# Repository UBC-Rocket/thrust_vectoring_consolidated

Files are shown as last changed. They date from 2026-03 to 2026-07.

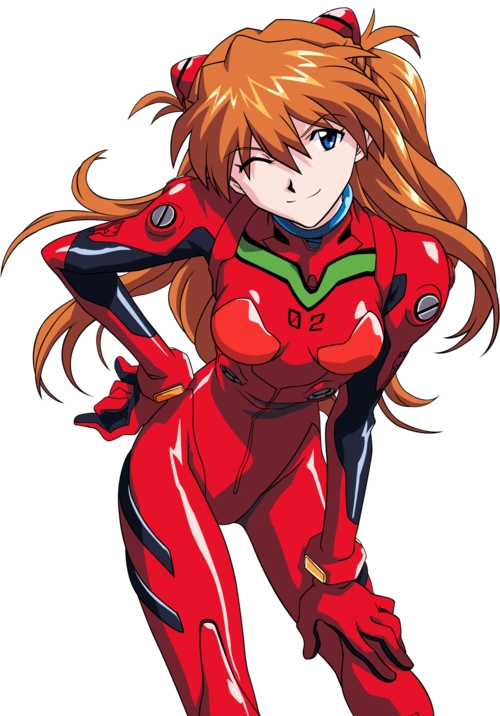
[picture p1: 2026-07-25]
embedded-software/ground-station/Resources/images/asuka.png

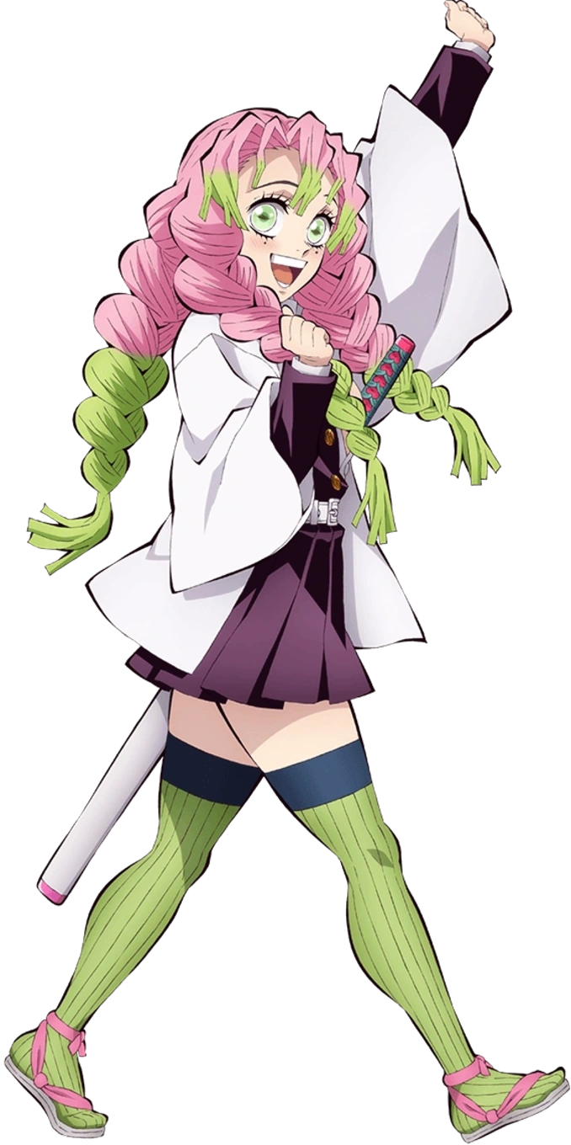
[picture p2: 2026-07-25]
embedded-software/ground-station/Resources/images/mitsuri.png

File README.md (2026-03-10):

# TVR - UBC Rocket







Mono-repo for the TVR project, containing firmware, ground station, shared libraries, and tools.

## Repository Structure

| Directory | Description |
|---|---|
| `embedded-software/firmware/ulysses-flight-controller/` | STM32H563 flight controller firmware (FreeRTOS, CMake) |
| `embedded-software/firmware/ulysses-gnss-radio/` | STM32G0xx GNSS/radio module firmware |
| `embedded-software/firmware/libs/` | Shared firmware libraries (EKF, controls, sensors, GPS) |
| `embedded-software/firmware/docs/` | Firmware documentation |
| `embedded-software/firmware/tools/` | SD log decoding and serial debug tools |
| `embedded-software/ground-station/` | Qt6/QML ground control station |
| `embedded-software/libs/rocket-protocol/` | Shared protobuf protocol library (nanopb, COBS, CRC) |
| `embedded-software/jetson/` | Future Jetson compute module (placeholder) |
| `controls/` | MATLAB/Simulink control system prototyping |
| `electrical-hardware/` | Electrical hardware design files |
| `mechanical-hardware/` | Mechanical hardware design files |

## Getting Started

For firmware development, open the board folder directly in VS Code:

- `embedded-software/firmware/ulysses-flight-controller/`
- `embedded-software/firmware/ulysses-gnss-radio/`

Each folder is self-contained with CMake presets, debug launch configs, and recommended extensions. See [embedded-software/firmware/docs/development_setup.md](embedded-software/firmware/docs/development_setup.md) for full setup instructions.

### Teams & Code Ownership

Each directory is owned by a subteam — see [CONTRIBUTING.md](CONTRIBUTING.md) for the branching model, team leads, and PR review requirements.

### Prerequisites

- ARM GCC toolchain (`arm-none-eabi-gcc`) for firmware
- STM32CubeIDE (for ST's OpenOCD — see [development setup](embedded-software/firmware/docs/development_setup.md))
- CMake 3.22+ and Ninja
- Qt 6.6+ for ground station
- Python 3.10+ with [uv](https://docs.astral.sh/uv/) for tools

### Environment Variables

Debugging requires two environment variables set in your shell profile (`~/.bashrc`, `~/.zshrc`, or `~/.config/fish/config.fish`). Both paths come from your STM32CubeIDE installation — the plugin version in the path varies by release.

| Variable | Purpose |
|---|---|
| `STM32_OPENOCD_PATH` | Path to the OpenOCD binary bundled with STM32CubeIDE |
| `STM32_OPENOCD_SCRIPTS_PATH` | Path to the OpenOCD st_scripts directory |

<details>
<summary>macOS</summary>

```bash
export STM32_OPENOCD_PATH="/Applications/STM32CubeIDE.app/Contents/Eclipse/plugins/com.st.stm32cube.ide.mcu.externaltools.openocd.macos64_<version>/tools/bin/openocd"
export STM32_OPENOCD_SCRIPTS_PATH="/Applications/STM32CubeIDE.app/Contents/Eclipse/plugins/com.st.stm32cube.ide.mcu.debug.openocd_<version>/resources/openocd/st_scripts"
```

</details>

<details>
<summary>Windows</summary>

```bash
export STM32_OPENOCD_PATH="D:/ST/STM32CubeIDE_<version>/STM32CubeIDE/plugins/com.st.stm32cube.ide.mcu.externaltools.openocd.win32_<version>/tools/bin/openocd.exe"
export STM32_OPENOCD_SCRIPTS_PATH="D:/ST/STM32CubeIDE_<version>/STM32CubeIDE/plugins/com.st.stm32cube.ide.mcu.debug.openocd_<version>/resources/openocd/st_scripts"
```

</details>

<details>
<summary>Linux</summary>

```bash
export STM32_OPENOCD_PATH="/opt/st/stm32cubeide_<version>/plugins/com.st.stm32cube.ide.mcu.externaltools.openocd.linux64_<version>/tools/bin/openocd"
export STM32_OPENOCD_SCRIPTS_PATH="/opt/st/stm32cubeide_<version>/plugins/com.st.stm32cube.ide.mcu.debug.openocd_<version>/resources/openocd/st_scripts"
```

</details>

> [!IMPORTANT]
> Restart VS Code (and your shell) after setting these variables.

### Building Firmware

```bash
cd embedded-software/firmware/ulysses-flight-controller
cmake --preset debug
cmake --build --preset debug
```

### Running Tests

```bash
# State estimation tests
cd embedded-software/firmware/libs/state_estimation/tests
cmake -B build && cmake --build build
ctest --test-dir build

# Controls tests
cd embedded-software/firmware/libs/controls/tests
cmake -B build && cmake --build build
ctest --test-dir build
```

### Building Ground Station

```bash
cd embedded-software/ground-station
cmake -B build
cmake --build build
```

## Releases

Tags follow the format `<component>/v<semver>`:
- `firmware-fc/v1.0.0` — Flight controller firmware
- `firmware-gnss/v1.0.0` — GNSS radio firmware
- `ground-station/v1.0.0` — Ground control station
- `tvr/v1.0.0` — Coordinated release of all components

## Contributors

<a href="https://github.com/UBC-Rocket/thrust_vectoring_consolidated/graphs/contributors">
  
</a>

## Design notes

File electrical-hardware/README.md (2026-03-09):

# Electrical Hardware

PCB designs, schematics, and release versions of TVR electrical hardware.

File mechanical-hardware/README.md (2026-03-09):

# Mechanical Hardware

CAD models and release versions of TVR mechanical hardware (.step files).

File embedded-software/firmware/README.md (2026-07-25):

# Firmware

All embedded firmware and shared libraries for the TVR project.

## Layer model

```
APP   app/                 hardware-agnostic tasks, state exchange, log service
DEV   dev/                 per-device drivers (opaque singletons)
IO    io/                  transport layer (SPI/UART/EXTI/DShot) +
                           system services (timestamp/intercore/LED/SD/init)
HW    flight_controller/   CubeMX project — STM32H747 dual-core (CM4 + CM7)
                           includes HAL, FreeRTOS, peripheral init
```

Plus:

| Top-level | Purpose |
|---|---|
| `lib/` | Pure-C utility libs (controls, state_estimation, log_records, …) |
| `sil/` | (placeholder) future POSIX SIL backend for the IO layer |
| `docs/` | Architecture proposals, peripheral notes, driver notes |
| `depracated/` | Old H5 flight controller + G0 GNSS daughter board, retained for reference |
| `tools/` | Host-side Python tools (SD log decoding, serial debug) |

## Building (on-target)

The CubeMX project at `flight_controller/` orchestrates two `ExternalProject`
sub-builds (one per core) for the STM32H745 dual-core target (CM7 + CM4).

```sh
./build.sh
./flash.sh    # requires STM32_OPENOCD_PATH and STM32_OPENOCD_SCRIPTS_PATH
```

`build.sh` accepts an optional preset (`Debug` or `Release`, default `Debug`) and
core filter (`both`, `cm7`, or `cm4`, default `both`). `flash.sh` uses the same
arguments to select which ELF(s) to program.

Equivalent raw CMake commands:

```sh
cd flight_controller
cmake --preset Debug && cmake --build --preset Debug
```

Each per-core build pulls in `io/`, `dev/`, `app/`, and `lib/` via
`add_subdirectory` — they don't need to be configured separately.

## Testing (host)

```sh
cd lib/controls/tests         && cmake -B build && cmake --build build && ./build/test_controls
cd lib/state_estimation/tests && cmake -B build && cmake --build build && ./build/test_state_estimation
```

## Further reading

- [`docs/architecture_layers.md`](docs/architecture_layers.md) — the HW / IO / DEV / APP layer proposal
- [`docs/spi_dma_overview.md`](docs/spi_dma_overview.md) — SPI job queue + DMA
- [`docs/sd_logging_overview.md`](docs/sd_logging_overview.md) — binary log design

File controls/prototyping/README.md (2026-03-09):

# Controls Prototyping

MATLAB/Simulink models and analysis scripts for control system design.

The production C implementations live in `firmware/libs/controls/` (PID controller, flight controller with torque control, control allocation, and gimbal angle computation).

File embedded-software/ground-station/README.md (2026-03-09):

# Ulysses Ground Control Station (GCS)
### *Real-Time Telemetry • Serial Radio Interface • 3D Rocket Visualization*

The **Ulysses Ground Control Station** is a cross-platform telemetry and control application built with **Qt 6**, designed for UBC Rocket's development and mission operations.  
It provides real-time serial communication with RFD900x radio modems, sensor telemetry decoding, 3D visual orientation, system alerts, and modular UI panels optimized for engineering workflows.

---

## 🚀 Features

### 📡 Dual-Mode Serial Communication

#### **1. Single-Port Mode**
- One COM port handles **both RX and TX**
- Automatic **RX pause** during TX to prevent echo/loopback issues
- Ideal for bench testing with a single modem

#### **2. Dual-Port Mode**
- Dedicated RX and TX ports
- Per-port capabilities:
  - Separate baud settings
  - Periodic command sender (1–200 Hz)
  - Manual send panel
  - Real-time text logging
  - Independent connect/disconnect

---

### 📶 RFD900x Modem Integration
- Automatic scanning of COM ports
- FTDI + CP210x radio-adapter detection
- AT-mode probing (`+++` guard sequence)
- OS error reporting displayed in UI
- Prevents assigning same port to both P1 and P2

---

### 📊 Sensor Telemetry Parsing

Incoming telemetry is 14-field CSV:
x, y, z,
roll, pitch, yaw,
pressure, altitude,
raw_angle, filtered_angle,
velocity, temperature, signal, battery

Decoded into:

- **IMU:** linear accel (x,y,z) + gyro (roll, pitch, yaw)
- **Barometer:** pressure, altitude
- **Kalman:** raw angle, filtered angle
- **Telemetry:** velocity, temperature, signal, battery

Each value updates QML-bound properties via `SensorDataModel`.

---

### 🛰️ 3D Rocket Visualization
Built with **Qt Quick 3D**:

- Real-time orientation driven by IMU data  
- Euler rotation mapped for Qt’s Y-up coordinate system  
- Axis helper lines  
- WASD camera movement  
- Clear visualization of rocket tilt/roll

---

### ⚠️ System Alert Classification
Using `AlarmReceiver`, incoming text is classified into:

- **ERROR**
- **WARNING**
- **SUCCESS**

Displayed visually as alert chips in the System Alert panel.

---

### 🧱 Modular Architecture

#### Backend (C++)
| Component | Description |
|---|---|
| `SerialBridge` | Serial I/O layer, port scanning, RX/TX, modem detection |
| `CommandSender` | Manual & periodic command transmission |
| `AlarmReceiver` | Classifies incoming text messages |
| `SensorDataModel` | Parses CSV telemetry, exposes data to QML |

#### Frontend (QML)
| File | Purpose |
|---|---|
| `Panel_Control.qml` | Serial configuration + TX console |
| `Panel_IMU_Data.qml` | IMU vector display |
| `Panel_Baro_And_Telemetry.qml` | Pressure, altitude, velocity, temp |
| `Panel_Rocket_Visualization.qml`  | 3D visualization of rocket |
| `Panel_System_Alert.qml` | Error/Warning/Success logs |
| `Items/` | Reusable UI components |

---

## 📁 Project Structure

/
├── src/
│ ├── SerialBridge.h/.cpp
│ ├── CommandSender.h/.cpp
│ ├── AlarmReceiver.h/.cpp
│ ├── SensorDataModel.h/.cpp
│ └── main.cpp
│
└── qml/
├── Panel_Control.qml
├── Panel_IMU_Data.qml
├── Panel_Baro_And_Telemetry.qml
├── Panel_Rocket_Visualization.qml
├── Panel_System_Alert.qml
├── Items/
└── MainWindow.qml

---

## 🧰 Build Instructions

### Requirements
- Qt **6.6+** (must include Qt Quick and Qt Quick 3D)
- CMake (Qt Creator recommended)
- Windows / macOS / Linux

### Build using Qt Creator
File → Open Project → CMakeLists.txt
Configure Kits → Desktop Qt 6.x.x
Build → Run

### Build using terminal
```bash
cmake -B build -S .
cmake --build build
./build/ulysses-ground-control     # or .exe on Windows

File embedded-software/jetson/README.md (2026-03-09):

# Jetson Compute Module

Placeholder for the future Jetson compute module. This will communicate with the flight controller via protobuf (transport TBD).

## Structure

- `src/` - Application code
- `deploy/` - Deployment scripts, Dockerfiles, flash utilities

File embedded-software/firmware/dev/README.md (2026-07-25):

# DEV layer

Per-device drivers. Each driver is a self-contained opaque singleton that
owns its EXTI handler, init sequence, sample ring, and IO bindings.

| Driver dir | Lib target | Header | Device | IO bindings |
|---|---|---|---|---|
| `imu_bmi088/` | `dev_imu_bmi088` | `dev_imu_bmi088.h` | Bosch BMI088 IMU | SPI4 + BMI_ACC_CS / BMI_GYRO_CS + INT1 lines |
| `imu_icm40609/`  | `dev_imu_icm40609`  | `dev_imu_icm40609.h`  | TDK InvenSense ICM-40609-D | SPI3 (HW NSS) + ICM_INT1 |
| `baro_ms5611/` | `dev_baro_ms5611` | `dev_baro_ms5611.h` | TE MS5611 barometer | SPI2 (HW NSS) |
| `gps_nmea/` | `dev_gps_nmea` | `dev_gps_nmea.h` | u-blox SAM-M10Q GPS (NMEA) | UART5, `'\n'` framing |
| `radio_rfd900/`  | `dev_radio_rfd900`  | `dev_radio_rfd900.h`  | RFDesign RFD900x telemetry | UART7, `0x00` framing |
| `servo_feetech/` | `dev_servo_feetech` | `dev_servo_feetech.h` | Feetech STS/SCS bus servos | UART8, half-duplex |
| `esc_dshot/` | `dev_esc_dshot` | `dev_esc_dshot.h` | DShot ESC pair | DShot upper/lower channels |

## API pattern

Every driver is an opaque singleton with the same five-call shape:

```c
#include "dev_imu_bmi088.h"

bool            imu_bmi088_init(void);                       /* IO bindings baked in */
imu_bmi088_t   *imu_bmi088_get (void);                       /* NULL before init */
size_t          imu_bmi088_drain(imu_bmi088_t *d, imu_sample_t *out, size_t max);
void            imu_bmi088_set_notify(imu_bmi088_t *d, io_task_handle_t t, uint32_t bit);
```

The struct is forward-declared in the public header; its definition lives
in the .c. Each driver references its IO transport symbols by name
(`IO_SPI_BMI088_ACC`, `IO_EXTI_BMI088_ACC_INT1`, …) which are declared in
`io/io_*.h` and defined per-target in `io/h747/CM{4,7}/`.

## Test hooks

Each driver's `s_self` singleton (and key scratch buffers, where applicable)
is exposed via `IO_TEST_HOOK_RW` / `IO_TEST_HOOK_ARRAY` macros from
[`io/io_sys/io_test_hooks.h`](../io/io_sys/include/io_sys/io_test_hooks.h).
The macros compile to nothing in production; tests link with
`-DIO_TEST_HOOKS` to access the underlying state.

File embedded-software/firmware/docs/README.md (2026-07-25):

# Firmware Documentation

Technical documentation for the TVR firmware.

- [Development Setup](development_setup.md) - Toolchain and environment setup
- [SPI DMA Overview](spi_dma_overview.md) - SPI bus architecture with DMA transfers
- [SD Logging Overview](sd_logging_overview.md) - Binary logging system design
- [Architecture: HW / IO / Dev / App Layers](architecture_layers.md) - Proposed layering and encapsulation (not yet approved)
- [Layer Hardening Proposal (v1)](layer_hardening_proposal.md) - **superseded** by `architecture_layers.md`
- `drivers/` - Sensor driver documentation
- `filtering/` - EKF and signal processing notes
- `peripherals/` - MCU peripheral configuration docs

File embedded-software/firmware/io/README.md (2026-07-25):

# IO layer

Transport between hardware peripherals and device drivers. Drivers and the
app code program against the headers in [`io/include/io/`](io/include/io/)
(transport — SPI, UART, EXTI, DShot) and [`io_sys/include/io_sys/`](io_sys/include/io_sys/)
(system services — timestamp, intercore, status LED, SD, init, shared types).

## Contents

| Path | What |
|---|---|
| `io/` | `io` interface lib — transport headers (DEV-only) |
| `io_sys/` | `io_sys` interface lib — system-service headers (APP + DEV) |
| `io_spi_queue/` | Generic SPI job-queue helper used by per-target SPI impls |
| `io_uart_dma_cm/` | DMA-circular + character-match UART helper |
| `io_intercore_slot/` | Seqlock shared-memory primitive for the H747 dual-core |
| `h747/CM4/` | H747 CM4 IO impl (defines IO_SPI_*, IO_UART_*, IO_EXTI_* symbols) |
| `h747/CM7/` | H747 CM7 IO impl |

## SIL substitution

The IO layer is the only place a SIL backend needs to replace. Add a peer
target dir (e.g. `sil/`) defining the same `IO_*` const symbols and the same
`io_*` functions; everything above (DEV, APP) links unchanged.

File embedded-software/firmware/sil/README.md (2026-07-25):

# SIL backend

Placeholder for a future POSIX/Linux software-in-the-loop implementation of
the IO layer. A SIL build mirrors `io/h747/` with simulated SPI, UART, EXTI,
and DShot impls; the `dev/` and `app/` layers above link unchanged.

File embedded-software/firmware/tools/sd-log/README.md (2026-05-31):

# SD Card Log Tools

Tools for decoding and visualizing flight log data from the SD card.

## Prerequisites

Install Python dependencies from the `tools/` directory:

```bash
cd embedded-software/firmware/tools
uv sync
```

## Decoding Binary SD Dumps

Extract the raw binary dump from the SD card, then decode it to JSONL:

```bash
# Decode a binary dump (auto-detect latest flight)
python sd-log/decode_log.py /path/to/dump.bin --latest-flight --output sd-log/logs/flight.jsonl

# Decode a specific flight by magic number
python sd-log/decode_log.py /path/to/dump.bin --flight-magic 0x5A5A5A5E --output sd-log/logs/flight.jsonl
```

The decoder validates CRC-16 checksums and outputs one JSON record per line.

## Viewing Flight Logs

Launch the interactive viewer on a decoded JSONL file:

```bash
cd embedded-software/firmware/tools/sd-log

# From a JSONL file path
uv run python -m viewer logs/flight.jsonl

# Or without arguments to get a file picker dialog
uv run python -m viewer
```

### Viewer Controls

- **Vertical scroll** (right side) — scroll through all graph rows
- **Pan** — drag left/right on any graph, or drag the highlighted region on the bottom scrubber
- **Zoom** — mouse wheel on any graph, or use the bottom zoom slider
- **Zoom slider** — logarithmic scale from microseconds to full flight duration
- **Time scrubber** — shows global time range and current viewport; drag edges to resize window

All graphs share the same time axis and stay synchronized.

### Graph Rows

The viewer displays separate rows for:

- Accelerometer (X, Y, Z)
- Gyroscope (X, Y, Z)
- Barometer 1 & 2 (pressure, temperature)
- State estimate: quaternion, position (NED), velocity (NED), angular rates
- Control output: commands, torques, attitude error, altitude
- GPS: position, quality metrics
- Events: arm/disarm, flight state changes, E-STOP (shown as vertical markers)

## Log Format

Each JSONL line contains:

```json
{
  "record_name": "accel_sample",
  "timestamp_us": 1482535,
  "payload": { "timestamp_us": 1482535, "ax_mps2": -1.64, "ay_mps2": -0.76, "az_mps2": 9.51 }
}
```

Record types are defined in `log_schema.py` (auto-generated from `log_records.h`).

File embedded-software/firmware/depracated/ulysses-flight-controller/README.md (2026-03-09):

# Ulysses

**Open-source flight controller firmware for UBC Rocket's experimental VTOL platform**

Ulysses powers UBC Rocket's Coaxial Counter-Rotating Vertical Take-off and Landing Drone — a testbed designed for developing and validating advanced rocket flight control algorithms in real-world conditions.

Built on the **STM32H563** (Cortex-M33, 250 MHz) running **FreeRTOS**, the firmware fuses IMU, barometer, and GPS data through an Extended Kalman Filter, drives a PID-based flight controller at 800 Hz, and communicates over a protobuf-based radio link.

## Table of Contents

- [Project Roadmap](#project-roadmap)
- [RTOS Architecture](#rtos-architecture)
- [Prerequisites](#prerequisites)
- [Building](#building)
- [Flashing and Debugging](#flashing-and-debugging)
- [Project Structure](#project-structure)
- [Contributing](#contributing)

## Project Roadmap

| Phase | Deliverables | Planned Completion |
|---|---|---|
| Phase 1 | Prototype capable of moving up, hovering, and landing | Jan 2026 |
| Phase 2 | Prototype capable of moving along a horizontal plane | May 2026 |
| Phase 3 | Swapping from PID to MPC control; FPGA integration; general polishing | Late 2026 |

## RTOS Architecture

The firmware runs four FreeRTOS tasks with the following priority hierarchy:

```
Priority High ──────────── Controls (800 Hz)
                           Debug Logging (optional)
Priority AboveNormal ───── State Estimation (event-driven)
Priority Normal ────────── Mission Manager (10 Hz telemetry)
```

### Controls Task

| | |
|---|---|
| **Priority** | High |
| **Rate** | 800 Hz (TIM4 interrupt-driven) |
| **Stack** | 2,048 bytes |

Runs the flight controller loop. Reads the latest fused state from the state exchange, computes attitude corrections (PD controller) and thrust commands (PID controller), and outputs PWM signals to servos (gimbal) and ESCs (motors). Includes a staleness check — outputs zero control if state data is too old.

### State Estimation Task

| | |
|---|---|
| **Priority** | AboveNormal |
| **Rate** | Event-driven (ISR notifications) |
| **Stack** | 2,048 bytes |

Fuses sensor data through a dual Extended Kalman Filter:
- **Orientation EKF** — quaternion state, driven by accelerometer and gyroscope
- **Body EKF** — position and velocity, driven by barometer and GPS

On startup, performs a calibration phase (20 samples) to compute gyro/accel biases. Publishes fused state (position, velocity, attitude, angular rate) to the shared state exchange. Logs all sensor samples and fused state to the SD card.

Responds to ISR flags: `BMI088_ACCEL_SAMPLE_FLAG`, `BMI088_GYRO_SAMPLE_FLAG`, `MS5611_BARO_SAMPLE_FLAG`, `MS5607_BARO2_SAMPLE_FLAG`, `GNSS_GPS_FIX_READY_FLAG`.

### Mission Manager Task

| | |
|---|---|
| **Priority** | Normal |
| **Rate** | 100 ms timeout / radio event |
| **Stack** | 2,048 bytes |

Manages the flight state machine and radio communications:

- **Flight states:** `IDLE` → `RISE` → `HOVER` → `LOWER` (or `E_STOP` at any time)
- **Radio RX:** Decodes protobuf `FlightCommand` messages (ARM, LAUNCH, ABORT, LAND, PID updates)
- **Radio TX:** Sends telemetry at 10 Hz and system status at 1 Hz
- **SD Logging:** Logs flight state transitions and periodically flushes the log buffer

### Debug Logging Task (optional)

| | |
|---|---|
| **Priority** | High |
| **Stack** | 512 bytes |
| **Enabled by** | `ULYSSES_ENABLE_DEBUG_LOGGING` (ON by default) |

Drains the debug log buffer and outputs formatted messages over USART1. Disable via the CMake option for production builds.

### Sensor Acquisition

Sensor data acquisition is handled asynchronously via DMA — no dedicated polling task is needed. SPI transfers for the BMI088 IMU, MS5611/MS5607 barometers, and GNSS radio run in the background and fire interrupts when data is ready, which notify the State Estimation task.

## Prerequisites

> **Windows is not supported.** The STM32CubeMX code generation uses forward slashes in paths, which breaks native Windows builds. If you're on Windows, use [WSL2](https://learn.microsoft.com/en-us/windows/wsl/install) with the Linux instructions below.

### Required Tools

| Tool | Version | Purpose |
|---|---|---|
| **ARM GNU Toolchain** | Latest (`arm-none-eabi-gcc`) | Cross-compiler for Cortex-M33 |
| **CMake** | >= 3.22 | Build system generator |
| **Ninja** | Latest | Build system |
| **STM32CubeIDE** | Latest | Provides ST's OpenOCD (required for STM32H563 support) |
| **Git** | Latest | Version control + submodules |

### Optional Tools

| Tool | Purpose |
|---|---|
| **STM32CubeMX** | GUI pin/peripheral configuration (edits `ulysses.ioc`) |
| **VS Code** | Recommended editor with Cortex-Debug integration |

### Install on macOS (Homebrew)

```bash
brew install --cask gcc-arm-embedded   # ARM toolchain
brew install cmake ninja git
```

STM32CubeIDE must be downloaded manually from [st.com](https://www.st.com/en/development-tools/stm32cubeide.html) (requires a free myST account).

### Install on Linux / WSL2

```bash
sudo apt update
sudo apt install gcc-arm-none-eabi cmake ninja-build git
```

Download STM32CubeIDE from [st.com](https://www.st.com/en/development-tools/stm32cubeide.html).

### Verify Installation

```bash
arm-none-eabi-gcc --version
cmake --version
ninja --version
```

## Building

### Clone the Repository

```bash
git clone https://github.com/UBC-Rocket/ulysses.git
cd ulysses
git submodule update --init --recursive
```

### Configure and Build (command line)

Using CMake presets (recommended):

```bash
# Debug build
cmake --preset debug
cmake --build --preset debug

# Release build
cmake --preset release
cmake --build --preset release
```

Or manually:

```bash
cmake -B build/debug \
  -DCMAKE_TOOLCHAIN_FILE=cmake/gcc-arm-none-eabi.cmake \
  -DCMAKE_BUILD_TYPE=Debug \
  -G Ninja

cmake --build build/debug
```

The output binary is `build/debug/ulysses.elf`.

### Build Options

| Option | Default | Description |
|---|---|---|
| `ULYSSES_ENABLE_DEBUG_LOGGING` | `ON` | Enable serial debug output over USART1 |
| `ULYSSES_USE_USB` | `OFF` | Enable USB support |

Pass options during configuration:

```bash
cmake --preset debug -DULYSSES_ENABLE_DEBUG_LOGGING=OFF
```

### Build with VS Code

1. Install the recommended extensions (open Command Palette → `Extensions: Show Recommended Extensions`)
2. VS Code will auto-detect `CMakePresets.json` — select `debug` or `release` when prompted
3. Click **Build** in the status bar or press `F7`

## Flashing and Debugging

Flashing and debugging require an **ST-Link** debugger connected to the board and **ST's OpenOCD** (bundled with STM32CubeIDE). Upstream OpenOCD does not yet support the STM32H563.

### Step 1: Set Up the OpenOCD Environment Variable

You need to set `STM32_OPENOCD_SCRIPTS_PATH` to point to the ST OpenOCD scripts directory inside your STM32CubeIDE installation.

**macOS:**

```bash
# Add to your ~/.zshrc, ~/.bashrc, or ~/.config/fish/config.fish
export STM32_OPENOCD_SCRIPTS_PATH="/Applications/STM32CubeIDE.app/Contents/Eclipse/plugins/com.st.stm32cube.ide.mcu.debug.openocd_2.3.200.202510310951/resources/openocd/st_scripts"
```

> The exact plugin version number (e.g. `2.3.200.202510310951`) will vary based on your STM32CubeIDE version. To find it:
> ```bash
> ls /Applications/STM32CubeIDE.app/Contents/Eclipse/plugins/ | grep openocd
> ```

**Linux / WSL2:**

```bash
# Add to your ~/.bashrc or ~/.zshrc
export STM32_OPENOCD_SCRIPTS_PATH="/opt/st/stm32cubeide_1.19.0/plugins/com.st.stm32cube.ide.mcu.debug.openocd_2.3.100.202501240831/resources/openocd/st_scripts"
```

> Find the exact path with:
> ```bash
> find /opt/st -path "*/openocd/st_scripts" -type d
> ```

**Important:** Restart your shell and VS Code after setting the variable.

### Step 2: Configure the OpenOCD Binary Path in VS Code

Create or edit `.vscode/settings.json`:

```json
{
  "cortex-debug.openocdPath": "<OPENOCD_BINARY_PATH>"
}
```

Where `<OPENOCD_BINARY_PATH>` is:

| Platform | Typical Path |
|---|---|
| **macOS** | `/Applications/STM32CubeIDE.app/Contents/Eclipse/plugins/com.st.stm32cube.ide.mcu.externaltools.openocd.macos64_2.4.200.202505051030/tools/bin/openocd` |
| **Linux** | `/opt/st/stm32cubeide_1.19.0/plugins/com.st.stm32cube.ide.mcu.externaltools.openocd.linux64_2.4.200.202505051030/tools/bin/openocd` |

> Find the exact path with:
> ```bash
> # macOS
> find /Applications/STM32CubeIDE.app -name "openocd" -type f
> # Linux
> find /opt/st -name "openocd" -type f
> ```

### Step 3: Flash and Debug

**From VS Code (recommended):**

1. Connect your ST-Link to the board
2. Open the **Run and Debug** panel (`Ctrl+Shift+D` / `Cmd+Shift+D`)
3. Select **Ulysses - Debug** or **Ulysses - Release**
4. Press `F5` to flash and start debugging
5. The debugger will halt at `main()` — press `F5` again to continue

The launch configurations use:
- **Interface:** `interface/stlink-dap.cfg`
- **Target:** `target/stm32h5x.cfg`
- **SVD:** `platform/svd/STM32H563.svd` (enables peripheral register inspection)

**From the command line (flash only):**

```bash
# Find the openocd binary (same path as OPENOCD_BINARY_PATH above)
OPENOCD=/path/to/openocd

$OPENOCD \
  -s "$STM32_OPENOCD_SCRIPTS_PATH" \
  -f interface/stlink-dap.cfg \
  -f target/stm32h5x.cfg \
  -c "program build/debug/ulysses.elf verify reset exit"
```

## Project Structure

```
ulysses/
├── Core/
│   ├── Inc/                        # Headers
│   │   ├── controls/               #   Flight controller, PID
│   │   ├── state_estimation/       #   EKF, quaternions, matrices
│   │   ├── motor_drivers/          #   PWM, ESC, servo drivers
│   │   ├── spi_drivers/            #   BMI088, MS5611, MS5607, GNSS radio
│   │   ├── SD_logging/             #   SD card logging
│   │   └── debug/                  #   Debug log facilities
│   └── Src/                        # Source files (mirrors Inc/ layout)
│       └── tasks/                  #   FreeRTOS task implementations
├── Drivers/                        # STM32 HAL & CMSIS (auto-generated)
├── Middlewares/                     # FreeRTOS kernel
├── rocket-protocol-lib/            # Protobuf radio protocol (submodule)
│   ├── generated/                  #   Nanopb-generated C code
│   ├── nanopb/                     #   Nanopb runtime library
│   └── src/                        #   Codec, COBS framing, CRC16
├── cmake/
│   ├── gcc-arm-none-eabi.cmake     # ARM Cortex-M33 toolchain file
│   ├── dependencies.cmake          # External deps (printf library)
│   └── stm32cubemx/                # CubeMX-generated CMake sources
├── docs/                           # Additional documentation
├── platform/svd/                   # SVD file for register debugging
├── tools/                          # SD card and serial utilities
├── CMakeLists.txt                  # Main build configuration
├── CMakePresets.json               # Build presets (debug/release)
├── ulysses.ioc                     # STM32CubeMX project configuration
├── STM32H563xx_FLASH.ld            # Linker script
└── startup_stm32h563xx.s           # MCU startup assembly
```

## Contributing

See [CONTRIBUTING.md](CONTRIBUTING.md) and the [Development Setup Guide](docs/development_setup.md) for detailed toolchain installation instructions.

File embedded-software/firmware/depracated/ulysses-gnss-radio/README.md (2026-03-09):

# Ulysses GNSS-Radio Slave Board

Dedicated GNSS receiver and radio transceiver slave board for the UBC Rocket Ulysses avionics system.

## Overview

The GNSS-Radio slave board interfaces with the Ulysses flight controller via SPI, providing:
- **GPS/GNSS positioning** with NMEA sentence u-blox SAM-M10Q
- **Radio communication** via RFD900x Radio Modem 
- **Dual-mode SPI protocol** (pull and push) for flexible data exchange
- **Debug injection system** for testing without physical peripherals (Debug builds only)

This board offloads GPS and radio communication from the main flight controller, reducing its processing burden and enabling deterministic real-time performance.

## Hardware

- **MCU**: STM32G0B1CEU6 (Cortex-M0+, 128KB FLASH, 144KB RAM)
- **Clock**: 16 MHz HSI (no PLL, low power configuration)
- **Peripherals**:
  - SPI1 (slave mode) - Communication with flight controller
  - USART5 (57600 baud) - Radio transceiver interface
  - USART6 (115200 baud) - GPS module interface
  - USART1 (115200 baud) - Debug console (ST-Link)
  - DMA1 (6 channels) - High-throughput peripheral data transfer
  - GPIO PB2 - IRQ output for push mode signaling

## Features

### SPI Slave Protocol
- **Pull Mode**: Master-initiated transactions with command-based protocol
  - Commands: 0x01-0x05 (radio read/write, GPS read, buffer status)
  - Transaction format: `[CMD:1][DUMMY:4][PAYLOAD:0-256]`
  - Total sizes: 6-261 bytes depending on command

- **Push Mode**: Slave-initiated data delivery via IRQ assertion
  - Slave asserts IRQ (PB2, active high) when data available
  - Transaction format: `[TYPE:1][PAYLOAD:N]`
  - Types: 0x01 (Radio), 0x05 (GPS)

- **Startup Configuration**: Dynamic mode selection on power-up
  - Master sends 8-byte configuration frame
  - Byte 0: Mode selection (0x00=Pull, 0x01=Push)
  - Bytes 1-7: GPS configuration (update rate, constellation, reserved)

### GPS Integration
- **Reception**: DMA circular + Character Match on '\n' via USART6
- **Parsing**: lwgps library (NMEA 0183 standard)
- **Supported sentences**: GPGGA, GPRMC, GPGSA, GPGSV (+ GLONASS variants)
- **Dual queue system**:
  - Raw NMEA queue: 10 samples × 87 bytes (pull mode)
  - Parsed fix queue: 10 fixes × 48 bytes (push mode)
- **Output formats**:
  - Pull mode: Raw NMEA sentences (up to 87 bytes)
  - Push mode: Parsed `gps_fix_t` struct (48 bytes, packed binary)

### Radio Integration
- **Interface**: UART5 at 57600 baud
- **Message size**: 256 bytes per message
- **Queue**: 10-message circular buffer
- **Read modes**:
  - FIFO (0x02): Oldest message first
  - LIFO (0x01): Newest message first (stack behavior)

### Debug Features (DEBUG builds only)
USART1 serves dual purpose when compiled with DEBUG macro:

**RX (Message Injection)**:
- Binary protocol for test message injection
- `0x52 ('R') + payload` → Inject radio message
- `0x47 ('G') + payload` → Inject GPS NMEA sentence
- Fully emulates real peripheral behavior via DMA + CM

**TX (System Logging)**:
- Human-readable event logging
- Log formats:
  - `[RADIO RX] <hex> (<ASCII>)` - Radio message received from UART5
  - `[GPS NMEA] <sentence>` - GPS NMEA sentence received from UART6
  - `[GPS FIX] Lat: X, Lon: Y, Alt: Z, ...` - Decoded GPS fix
  - `[SPI TX] Radio msg from master: <hex>` - Radio TX from SPI master
  - `[SPI->M] Radio: <hex> (<ASCII>)` - Radio message sent to SPI master
  - `[SPI->M] GPS: <data>` - GPS data sent to SPI master
  - `[SPI->M] BufLen: <count>` - Buffer length response sent to SPI master
- Zero code size impact in Release builds

## Build System

### Prerequisites
- CMake 3.16+
- Ninja build system
- arm-none-eabi-gcc toolchain
- Git (for lwgps submodule)

### Building

```bash
# Initialize lwgps submodule (first time only)
git submodule update --init --recursive

# Debug build (with injection and logging)
cmake --preset Debug
ninja -C build/Debug

# Release build (production, no debug features)
cmake --preset Release
ninja -C build/Release
```

### Build Configuration
- **Debug preset**: Defines `DEBUG` macro, enables debug UART features
- **Release preset**: Stripped binary, no debug overhead
- **C standard**: C11 with GNU extensions
- **Optimization**: `-Og` (Debug), `-O2` (Release)

## Project Structure

```
ulysses-gnss-radio/
├── Core/
│   ├── Inc/                        # Header files
│   │   ├── main.h
│   │   ├── protocol_config.h       # SPI protocol definitions & structs
│   │   ├── spi_slave.h             # SPI slave driver API
│   │   ├── gps.h                   # GPS driver API
│   │   ├── gps_nema_queue.h        # Raw NMEA queue
│   │   ├── gps_fix_queue.h         # Parsed fix queue
│   │   ├── radio_driver.h          # Radio transceiver API
│   │   ├── radio_queue.h           # Radio message queue
│   │   ├── debug_uart.h            # Debug injection/logging (DEBUG only)
│   │   └── uart_callbacks.h        # UART interrupt routing
│   │
│   └── Src/                        # Implementation files
│       ├── main.c                  # Initialization & main loop
│       ├── spi_slave.c             # SPI slave driver (register-level)
│       ├── gps.c                   # GPS NMEA receiver & parser
│       ├── radio_driver.c          # Radio transceiver interface
│       ├── debug_uart.c            # Debug injection/logging
│       ├── uart_callbacks.c        # UART interrupt routing
│       └── stm32g0xx_hal_msp.c     # HAL MSP init (CubeMX generated)
│
├── lib/lwgps/                      # lwgps NMEA parser (git submodule)
├── Drivers/                        # STM32 HAL drivers (CubeMX generated)
├── CMakeLists.txt                  # Build configuration
├── CMakePresets.json               # Debug/Release presets
└── ulysses-gnss-radio.ioc         # STM32CubeMX project file
```

## SPI Slave Implementation Deep Dive

This section explains the low-level implementation details of the SPI slave driver, which uses register-level programming for maximum performance and determinism.

### Architecture Overview

The SPI slave uses a **hybrid RXNE interrupt + DMA approach**:
- **First byte (command)**: Captured by RXNE interrupt for fast response
- **Remaining bytes**: Handled by DMA for zero CPU overhead
- **Transaction completion**: Detected via NSS rising edge (EXTI interrupt)

This architecture provides a 4-byte time window to decode the command and prepare the response before the master clocks out the data region.

### Peripheral Initialization Note

**IMPORTANT**: The SPI peripheral initialization uses the STM32 HAL layer (`stm32g0xx_hal_msp.c`) to configure GPIO pins, enable clocks, and reserve the SPI1 peripheral. This HAL-based initialization ensures proper peripheral reservation and avoids conflicts with other code that might try to use SPI1.

After HAL initialization completes, the SPI slave driver ([spi_slave.c](Core/Src/spi_slave.c)) takes over and uses **register-level programming** for all runtime operations. The HAL is only used during startup to:
- Configure SPI1 GPIO pins (PA4-PA7) in alternate function mode
- Enable peripheral clocks (SPI1, DMA1, DMAMUX, GPIOA, GPIOB)
- Set up NVIC interrupt priorities

This hybrid approach (HAL for init, registers for runtime) provides the best of both worlds: HAL's initialization convenience and register-level performance for time-critical operations.

### Why 4 Dummy Bytes?

The implementation uses **4 dummy bytes** (not 2) to avoid a TX FIFO prefetch race condition:

1. STM32G0 SPI peripheral has a 4-byte TX FIFO
2. When master starts clocking, slave TX FIFO immediately pulls 4 bytes from DMA
3. **Critical timing constraint**: We must patch the TX buffer with response data BEFORE those 4 bytes are consumed
4. By placing response data starting at byte 5 (after CMD + 4 DUMMY), we guarantee the RXNE ISR has time to prepare the response

**Timing breakdown** (at 1 MHz SPI clock):
- Command byte arrives: RXNE ISR fires (~1 µs)
- Decode command + patch TX buffer: ~10-20 µs (worst case)
- Dummy bytes consumed: 4 bytes × 8 µs/byte = 32 µs
- **Result**: 32 µs window is sufficient for even worst-case command handling

### Pull Mode Implementation

Pull mode uses **master-initiated transactions** with command-based protocol.

#### State Machine (Pull Mode)
```
UNCONFIGURED ──[config frame]──> IDLE ──[NSS↓]──> ACTIVE ──[NSS↑]──> IDLE
                                    ↑                                    │
                                    └────────────────────────────────────┘
```

#### Transaction Flow (Pull Mode)

**Step 1: Idle State (Waiting)**
- `SPI_STATE_IDLE`
- TX DMA armed with 261-byte buffer (zeros initially)
- RX DMA configured but **RXDMAEN disabled** (critical!)
- **RXNEIE enabled** - waiting for first byte interrupt

**Step 2: Command Byte Arrival**
- NSS falls (master starts transaction)
- First byte clocked in → SPI RXNE flag set
- `SPI1_IRQHandler()` fires (highest priority interrupt)
- **Critical section** (~10-20 µs):
  ```c
  cmd = SPI1->DR;  // Read command byte (clears RXNE)
  ctx.current_cmd = cmd;

  // Patch TX buffer based on command
  switch (cmd) {
    case CMD_RADIO_RX_FIFO:
      memcpy(&tx_buf[5], radio_msg, 256);  // Offset 5 = skip cmd+dummy
      break;
    // ... other commands
  }

  // NOW enable RX DMA (handoff to DMA for remaining bytes)
  SPI1->CR2 |= SPI_CR2_RXDMAEN;
  ```
- **Disable RXNEIE** - no more byte interrupts
- **Enable RXDMAEN** - DMA takes over for bytes 1-260

**Step 3: DMA Takes Over**
- State transitions to `SPI_STATE_ACTIVE`
- RX DMA silently captures bytes 1-260 into `rx_buf[1..260]`
- TX DMA silently sends bytes 0-260 from `tx_buf[0..260]`
- **Zero CPU overhead** from this point on

**Step 4: Transaction Complete**
- NSS rises (master done)
- EXTI4_15 interrupt fires (NSS rising edge on PA4)
- Process write commands (e.g., CMD_RADIO_TX extracts payload from rx_buf)
- Re-arm for next transaction: `spi_slave_arm()`

#### Pull Mode Register Configuration
```c
// Initial setup (waiting for command)
SPI1->CR2 = (7 << SPI_CR2_DS_Pos)    // 8-bit frames
          | SPI_CR2_FRXTH            // 1-byte RX threshold (trigger RXNE every byte)
          | SPI_CR2_RXNEIE           // RXNE interrupt enabled
          | SPI_CR2_TXDMAEN;         // TX DMA enabled (RX DMA OFF initially!)

// After command captured (in RXNE ISR)
SPI1->CR2 |= SPI_CR2_RXDMAEN;        // Enable RX DMA (handoff from interrupt)
```

### Push Mode Implementation

Push mode uses **slave-initiated transactions** via IRQ assertion.

#### State Machine (Push Mode)
```
IDLE ──[data available]──> HAVE_DATA ──[NSS↓]──> ACTIVE ──[NSS↑]──> IDLE
                              (IRQ↑)                          (IRQ↓)
```

#### Transaction Flow (Push Mode)

**Step 1: Data Becomes Available**
- GPS fix parsed or radio message received
- `spi_slave_tick()` called from main loop
- Detects pending data in queue
- Calls `spi_slave_prepare_push(PUSH_TYPE_GPS)`:
  ```c
  tx_buf[0] = PUSH_TYPE_GPS;  // Type byte
  memcpy(&tx_buf[1], &gps_fix, 48);  // GPS fix payload
  ctx.tx_dma_length = 49;  // Total bytes to send
  ```
- Arms **both TX and RX DMA** simultaneously
- Asserts **IRQ line (PB2 high)**
- State transitions to `SPI_STATE_HAVE_DATA`

**Step 2: Master Responds to IRQ**
- Master detects IRQ rising edge
- Master asserts NSS (starts SPI transaction)
- **Both DMAs active from start** (different from pull mode!)
  - TX DMA sends prepared buffer (type + payload)
  - RX DMA captures what master sends (might be zeros, might be radio TX)

**Step 3: Transaction Complete**
- NSS rises
- `spi_slave_nss_exti_handler()` fires
- **Deassert IRQ (PB2 low)**
- Check RX buffer for valid data:
  ```c
  if (rx_received >= 256 && spi_slave_rx_has_valid_data()) {
    // Master sent radio TX simultaneously! Enqueue it.
    radio_message_enqueue(256, rx_buf, radio_queue);
  }
  ```
- Pop transmitted message from queue
- Re-arm for next transaction

#### Push Mode Register Configuration
```c
// Armed for push transaction (both DMAs active)
SPI1->CR2 = (7 << SPI_CR2_DS_Pos)    // 8-bit frames
          | SPI_CR2_FRXTH            // 1-byte RX threshold
          | SPI_CR2_TXDMAEN          // TX DMA enabled
          | SPI_CR2_RXDMAEN;         // RX DMA enabled (both on from start!)
// Note: RXNEIE is OFF in push mode (no command byte to capture)
```

### Key Differences: Pull vs Push

| Aspect | Pull Mode | Push Mode |
|---|---|---|
| **Initiator** | Master (via command) | Slave (via IRQ) |
| **RXNEIE** | Enabled (capture command) | Disabled (no command byte) |
| **RXDMAEN** | Enabled AFTER command | Enabled from start |
| **TX Buffer** | Patched in RXNE ISR | Pre-loaded before IRQ assert |
| **IRQ Line** | Not used | Asserted when data ready |
| **Transaction Length** | Variable (6-261 bytes) | Fixed per type (49 or 257 bytes) |

### DMA Configuration Details

The implementation uses **DMA1 with DMAMUX routing**:

**RX DMA (Channel 1)**:
```c
DMA1_Channel1->CCR = DMA_CCR_MINC         // Increment memory address
                   | DMA_CCR_TCIE         // Transfer complete interrupt
                   | DMA_CCR_TEIE         // Transfer error interrupt
                   | (2 << DMA_CCR_PL_Pos); // High priority (RX critical!)
```

**TX DMA (Channel 2)**:
```c
DMA1_Channel2->CCR = DMA_CCR_DIR          // Memory → Peripheral
                   | DMA_CCR_MINC         // Increment memory address
                   | (1 << DMA_CCR_PL_Pos); // Medium priority
```

**DMAMUX Routing**:
```c
DMAMUX1_Channel0->CCR = 16;  // SPI1_RX request (RM0444 Table 59)
DMAMUX1_Channel1->CCR = 17;  // SPI1_TX request
```

### NSS Edge Detection (EXTI)

Transaction completion is detected via **NSS rising edge** on PA4:

```c
// Route PA4 to EXTI line 4
EXTI->EXTICR[1] = (0x00 << 0);  // Port A = 0x00

// Enable rising edge detection
EXTI->RTSR1 |= (1 << 4);  // Rising edge on line 4

// Unmask interrupt
EXTI->IMR1 |= (1 << 4);
```

**Why EXTI instead of SPI NSS interrupt?**
- STM32G0 SPI peripheral doesn't have a dedicated NSS interrupt
- EXTI provides precise timing for NSS rising edge detection
- Allows us to know exactly when master releases the bus

### Collision Handling (Push Mode)

**Scenario**: Slave asserts IRQ, but master was already starting a radio TX transaction.

**Detection**: Check RX buffer pattern after push transaction:
```c
bool spi_slave_rx_has_valid_data(void) {
  uint16_t zeros = 0, ones = 0;
  for (int i = 0; i < 16; i++) {  // Sample first 16 bytes
    if (rx_buf[i] == 0x00) zeros++;
    if (rx_buf[i] == 0xFF) ones++;
  }
  // If >14 bytes are dummy (0x00 or 0xFF), it's not real data
  return (zeros + ones) < 14;
}
```

**Resolution**: If valid data detected, enqueue it as a radio TX message.

### Interrupt Priorities

Critical for correct operation:

| Interrupt | Priority | Rationale |
|---|---|---|
| SPI1_IRQn (RXNE) | 0 (highest) | Must capture command within 4-byte window |
| DMA1_Channel1_IRQn | 1 (high) | Process RX data quickly |
| EXTI4_15_IRQn (NSS) | 2 (normal) | Transaction cleanup can wait |

### Buffer Alignment

Both TX and RX buffers are **32-byte aligned** for optimal DMA performance:
```c
uint8_t tx_buf[MAX_TRANSACTION_SIZE] __attribute__((aligned(32)));
uint8_t rx_buf[MAX_TRANSACTION_SIZE] __attribute__((aligned(32)));
```

**Why 32 bytes?** STM32G0 DMA works best with cache-line aligned buffers (even though G0 has no D-cache, alignment helps bus arbitration).

## SPI Protocol Reference

### Configuration Frame (Startup)
```
Master → Slave (on power-up):
  [MODE:1][GPS_RATE:1][GPS_CONSTELLATION:1][RESERVED:5]

MODE: 0x00 = Pull mode, 0x01 = Push mode
GPS_RATE: Update rate in Hz (e.g., 1, 5, 10)
GPS_CONSTELLATION: Bitmask for GNSS constellations
```

### Pull Mode Commands
| Code | Command | Direction | Payload | Total Size | Description |
|---|---|---|---|---|---|
| 0x01 | RADIO_RX_LIFO | Slave→Master | 256 B | 261 B | Newest radio message |
| 0x02 | RADIO_RX_FIFO | Slave→Master | 256 B | 261 B | Oldest radio message |
| 0x03 | RADIO_RXBUF_LEN | Slave→Master | 1 B | 6 B | Message count (0-255) |
| 0x04 | RADIO_TX | Master→Slave | 256 B | 261 B | Transmit radio message |
| 0x05 | GPS_RX | Slave→Master | 87 B | 92 B | Raw NMEA sentence |

### Push Mode Data Types
| Type | Data Type | Payload | Total Size | Description |
|---|---|---|---|---|
| 0x01 | RADIO | 256 B | 257 B | Radio message ready |
| 0x05 | GPS | 48 B | 49 B | Parsed GPS fix (gps_fix_t) |

### Transaction Timing
- **Dummy bytes**: 4 bytes (critical for TX FIFO prefetch race avoidance)
- **IRQ assertion**: Active high on PB2
- **IRQ deassert**: Automatic on transaction complete (NSS rising edge)

## GPS Fix Structure (gps_fix_t)

```c
typedef struct {
    double   latitude;         // Degrees (-90 to +90)           [8 bytes]
    double   longitude;        // Degrees (-180 to +180)         [8 bytes]
    float    altitude_msl;     // Meters above sea level         [4 bytes]
    float    ground_speed;     // m/s                            [4 bytes]
    float    course;           // Degrees true north (0-360)     [4 bytes]
    uint8_t  fix_quality;      // 0=invalid, 1=GPS, 2=DGPS       [1 byte]
    uint8_t  num_satellites;   // Number of satellites used      [1 byte]
    uint8_t  padding1[2];      // Alignment                      [2 bytes]
    float    hdop;             // Horizontal dilution            [4 bytes]
    uint32_t time_of_week_ms;  // GPS time of week (ms)          [4 bytes]
    uint8_t  padding2[8];      // Future use                     [8 bytes]
} __attribute__((packed)) gps_fix_t;  // Total: 48 bytes
```

## Memory Usage

**Debug build** (with injection & logging):
- FLASH: 28.4 KB (22.2% of 128 KB)
- RAM: 11.9 KB (8.1% of 144 KB)

**Release build** (production):
- FLASH: ~26 KB (estimated, no debug overhead)
- RAM: ~10 KB (estimated)

## Testing

### Hardware Testing
1. Connect ST-Link programmer to SWD pins
2. Flash firmware: `cmake --preset Debug && ninja -C build/Debug && st-flash write build/Debug/ulysses-gnss-radio.bin 0x08000000`
3. Monitor UART1 output for startup message

### Debug Injection Testing
Use a serial terminal (e.g., minicom, screen, PuTTY) connected to USART1:

```bash
# Inject radio message "Hello"
echo -ne '\x52Hello\x00' > /dev/ttyUSB0

# Inject GPS NMEA sentence
echo -ne '\x47$GPGGA,123519,4807.038,N,01131.000,E,1,08,0.9,545.4,M,46.9,M,,*47\r\n' > /dev/ttyUSB0
```

Monitor log output to verify messages are enqueued and processed correctly.

### SPI Protocol Testing
Use a logic analyzer or oscilloscope to verify:
- Configuration frame reception on startup
- Pull mode command responses
- Push mode IRQ assertion timing
- DMA transfer completion

## Configuration

### Changing SPI Mode
The operational mode is selected via configuration frame on startup. The flight controller must send the config frame immediately after power-up before normal SPI communication.

### GPS Configuration
GPS update rate and constellation selection can be configured via the configuration frame (bytes 1-2). Implementation of these features depends on GPS module capabilities.

## Troubleshooting

**Problem**: "Awaiting configuration from master" message persists
**Solution**: Master must send 8-byte configuration frame on startup

**Problem**: GPS not parsing NMEA sentences
**Solution**: Check USART6 baud rate (should be 115200), verify GPS module TX connection

**Problem**: Radio messages not received
**Solution**: Verify USART5 baud rate (57600), check radio module UART connection

**Problem**: Debug injection not working
**Solution**: Ensure firmware built with Debug preset (DEBUG macro defined)

## References

- **SPI Protocol**: See `spi_timing.html` (deprecated - contains some inaccuracies)
- **Protocol Definitions**: [Core/Inc/protocol_config.h](Core/Inc/protocol_config.h)
- **GPS Parser**: [lib/lwgps/README.md](lib/lwgps/README.md)
- **STM32G0 Reference**: RM0444 (STM32G0x1 reference manual)

## Contributing

This is part of the UBC Rocket avionics system. For questions or contributions, contact the UBC Rocket Avionics team.

## License

[Add license information here]

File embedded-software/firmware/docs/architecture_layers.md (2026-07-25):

# HW / IO / Dev / App Layer Architecture

**Status:** implemented (originally proposed 2026-05-16).
**Supersedes:** [layer_hardening_proposal.md](layer_hardening_proposal.md) (v1) — v1 proposed "app does the IO wiring", which we rejected in favour of self-contained device drivers.

> **Note on paths.** The proposal section below uses the as-proposed names
> for clarity. The implementation made a few small adjustments to keep IO
> helper libs consistent: `libs/spi_queue` → `io/io_spi_queue`,
> `libs/uart_dma_cm` → `io/io_uart_dma_cm`, `libs/intercore` →
> `io/io_intercore_slot`. DEV files are flat (`dev/imu_bmi088/include/dev_imu_bmi088.h`).
> Per-target IO impl filenames dropped the `_cm{4,7}` suffix
> (`io/h747/CM4/io_timestamp.c`) since the parent directory already
> conveys the core.

---

## The model

Four layers, bottom-up. The arrows are "may call"; nothing reaches sideways or downward across more than one layer.

```
┌─────────────────────────────────────────────────────────────────┐
│                              APP                                │
│         (FreeRTOS tasks, state exchange, mission FSM,           │
│          log service, controls glue)                            │
├────────────────────────────▲────────────────────────────────────┤
│                              │                                  │
│                              ▼                                  │
│                              DEV                                │
│      (per-device drivers: imu_bmi088, imu_icm40609,             │
│       baro_ms5611, gps_nmea, radio_rfd900, esc_dshot,           │
│       servo_feetech — each self-contained, knows its            │
│       own peripheral wiring)                                    │
├────────────────────────────▲────────────────────────────────────┤
│                              │                                  │
│                              ▼                                  │
│                              IO                                 │
│      (target-specific peripheral utilities:                     │
│       SPI job queue + DMA callbacks, UART DMA + char-match,     │
│       EXTI dispatch, DShot bit-bang, SDMMC async writer,        │
│       timestamp source, inter-core HSEM + shared memory)        │
├────────────────────────────▲────────────────────────────────────┤
│                              │                                  │
│                              ▼                                  │
│                              HW                                 │
│      (ST HAL, CubeMX-generated peripheral init, GPIO mux,       │
│       clock tree, TIM / DMA primitives)                         │
└─────────────────────────────────────────────────────────────────┘
```

What each layer **owns**:

| Layer | Owns | Touches downward | Does **not** touch |
|---|---|---|---|
| **APP** | Tasks, scheduling glue, mission state, state exchange, logging | DEV drivers, IO system services (timestamp, intercore) | IO transports (SPI/UART/EXTI/DShot), HW |
| **DEV** | Device protocol, calibration defaults, EXTI handler, sample ring, init sequence — **all per-device config baked in** | IO layer by symbolic resource name (`IO_SPI_BMI088_ACC`, `IO_EXTI_BMI088_INT1`, …) | HW directly |
| **IO** | DMA pipelines, peripheral callbacks, per-peripheral resource symbols, timestamps, intercore, status LEDs | HW (ST HAL) | DEV, APP |
| **HW** | Bare-metal peripheral init, register-level wiring, clock setup | — | anything above |

Why this carving:
- **Drivers are self-contained.** A driver knows it talks to "BMI088 accel on SPI4 with CS on PE3 and INT on PC13", because that's a property of the board, and the board is fixed. The app doesn't pick the wiring at boot — it doesn't need to.
- **IO is the SIL substitution boundary.** Swap `io/h747/` for `io/sil/`; the symbols a driver references (`IO_SPI_BMI088_ACC`, etc.) resolve to a simulated peripheral that returns canned register responses. The driver source is unchanged.
- **App never sees a `HAL_*` symbol, never sees `hspi4`, never sees a CS pin.** The most it sees is `io_timestamp_us()`.

---

## Resource binding: symbolic, owned by IO

Drivers don't accept config structs. They reference IO resources by name:

```c
/* dev/imu_bmi088/imu_bmi088.c */
#include "io/io_spi.h"
#include "io/io_exti.h"

extern const io_spi_dev_t   IO_SPI_BMI088_ACC;
extern const io_spi_dev_t   IO_SPI_BMI088_GYRO;
extern const io_exti_line_t IO_EXTI_BMI088_ACC_INT1;
extern const io_exti_line_t IO_EXTI_BMI088_GYRO_INT1;

static struct {
    /* per-driver state: queue, sample ring, notify target, dev regs */
} s_self;

static void on_acc_data_ready(void *user) { /* submit SPI read */ }

bool imu_bmi088_init(void) {
    io_exti_register(&IO_EXTI_BMI088_ACC_INT1, on_acc_data_ready, &s_self);
    /* … config sequence via io_spi_xfer_blocking(&IO_SPI_BMI088_ACC, …) */
    return true;
}
```

The resource symbols are defined by the per-target IO layer:

```c
/* io/h747/cm4/io_spi_resources.c */
const io_spi_dev_t IO_SPI_BMI088_ACC = {
    .bus     = &g_spi4_bus,          /* file-private spi_queue instance */
    .cs_port = GPIOE,
    .cs_pin  = GPIO_PIN_3,
};
const io_spi_dev_t IO_SPI_BMI088_GYRO = {
    .bus     = &g_spi4_bus,
    .cs_port = GPIOE,
    .cs_pin  = GPIO_PIN_4,
};
/* … */
```

Swap target:
```c
/* io/sil/io_spi_resources.c */
const io_spi_dev_t IO_SPI_BMI088_ACC = {
    .sim = &g_sim_bmi088_acc,        /* simulator handle */
};
```

The driver doesn't notice. **What changes between targets is the IO layer's symbol table.** The driver source is target-independent code that happens to reference target-defined symbols.

Calibration values that *do* vary per assembly (servo trim, IMU bias, baro reference) come from a non-volatile config service (flash sector / SD card) at runtime, not from compile-time config structs. The driver carries the defaults; the config service may override.

---

## What this means for the current tree

Renames:

| Today | After |
|---|---|
| `libs/bsp/` (interface headers) | `libs/io/` |
| `libs/bsp/include/bsp/bsp_*.h` | `libs/io/include/io/io_*.h` |
| `libs/drivers/` | `libs/dev/` |
| `libs/drivers/<x>/include/drivers/<x>.h` | `libs/dev/<x>/include/dev/<x>.h` |
| `firmware/flight_controller/CM{4,7}/Bsp/` | `firmware/flight_controller/CM{4,7}/Io/` |
| `bsp_init_cm{4,7}()` | `io_init_cm{4,7}()` |
| `bsp_kernel_start()` | stays at top level, e.g. `app_start_kernel()` (it's a scheduler hand-off, not an IO concern) |

The `libs/sensors/` parser helpers stay where they are — they sit at the same level as a vendor driver would (pure C, no I/O), and the DEV layer pulls them in.

`libs/spi_queue/`, `libs/uart_dma_cm/`, `libs/intercore/` are implementation details of the IO layer; they remain separate libs so they can be unit-tested, but they only ever link into IO impl files. They are not in the public IO API.

---

## Moves

### Move 1 — Privatise every global; expose getters only

Anything currently at module scope without `static` becomes `static`. If something outside the TU needs access, it gets a getter.

Concrete targets:
- `app/cm7/app_init_cm7.c` — `g_servos`, `g_escs` become file-private statics. Access via `actuators_handles()` from a new `app/cm7/actuators_init.{c,h}`, mirror of [sensors_init.h](../app/include/app/sensors_init.h).
- Audit and fix any other `extern`-able definition. (Grep target: `^[A-Za-z_].* [a-z][a-zA-Z_0-9]+ *=`.)
- DEV drivers themselves: since each driver becomes singleton-by-design (Move 2), the only "global" is the singleton struct, which is `static` inside the .c.

### Move 2 — DEV drivers are opaque singletons; no caller-allocated structs

Driver public header exposes only the API. The state struct is forward-declared and defined in the .c.

```c
/* libs/dev/imu_bmi088/include/dev/imu_bmi088.h */
typedef struct imu_bmi088 imu_bmi088_t;     /* opaque */

bool                 imu_bmi088_init(void);
size_t               imu_bmi088_drain(imu_sample_t *out, size_t max);
void                 imu_bmi088_set_notify(io_task_handle_t task, uint32_t bit);
const imu_bmi088_t  *imu_bmi088_get(void);   /* NULL before init */
```

```c
/* libs/dev/imu_bmi088/src/imu_bmi088.c */
struct imu_bmi088 { /* private fields */ };
static struct imu_bmi088 s_self;
```

App code references the driver only by these calls; it never allocates an `imu_bmi088_t`.

`sensors_t` / `actuators_t` view-structs in the APP layer become read-only pointer bundles populated from `imu_bmi088_get()` etc., for ergonomics in task code.

### Move 3 — DEV drivers carry their own peripheral binding

No more `imu_bmi088_cfg_t` / `servo_feetech_cfg_t` from the caller. The driver `.c` file is the single source of truth for "which peripheral this device is on". The driver references IO resource symbols directly (extern-declared from `io/<target>/`).

```c
/* libs/dev/servo_feetech/src/servo_feetech.c */
#include "io/io_uart.h"
extern const io_uart_id_t IO_UART_SERVO_BUS;

static const uint8_t SERVO_ID_X = 1;
static const uint8_t SERVO_ID_Y = 2;
static const uint16_t POS_MIN   = 1024;
static const uint16_t POS_MID   = 2048;
static const uint16_t POS_MAX   = 3072;
static const float    DEG_RANGE = 90.0f;
```

This is the user-requested correction to v1: **config lives in the driver, not in the caller**.

Tradeoff accepted: porting a driver to a new board requires editing the driver. That's fine — different board, different driver. The protocol layer (`libs/sensors/bmi088_*.c`) is the part that's board-independent and stays reusable.

### Move 4 — Rename `bsp` → `io`, `drivers` → `dev`

Mechanical rename. Headers move from `bsp/` → `io/`, `drivers/` → `dev/`. Update include paths everywhere. Update CMake target names (`bsp` → `io`, `drivers_imu_bmi088` → `dev_imu_bmi088`, etc.). The HW layer keeps living inside `flight_controller/CM{4,7}/Core/` (CubeMX-generated, untouched).

### Move 5 — Split IO surfaces by who's allowed to see them

Two interface namespaces inside the IO layer:

```
libs/io/include/
├── io/             # transports — DEV only
│   ├── io_spi.h
│   ├── io_uart.h
│   ├── io_exti.h
│   ├── io_dshot.h
│   ├── io_sd.h
│   └── io_types.h
└── io_sys/         # system services — APP and DEV
    ├── io_timestamp.h
    ├── io_intercore.h
    ├── io_status_led.h
    └── io_init.h
```

CMake link rules (Move 6) prevent APP from `#include`-ing transport headers.

### Move 6 — Tighten CMake link visibility

| Target | PUBLIC link | PRIVATE link |
|---|---|---|
| `io` (interface) | — | — |
| `io_sys` (interface) | — | — |
| `spi_queue`, `uart_dma_cm`, `intercore` | `stm32cubemx` | — |
| `dev_<name>` (each device driver) | `io_sys` | `io`, `sensors`, `spi_queue`/`uart_dma_cm` as needed |
| `app_shared` | `io_sys`, `state_estimation`, `log_records`, … | — |
| `app_cm{4,7}` | `app_shared`, `io_sys`, `dev_*` | — |
| per-core executable | — | `io` (only because it compiles the IO impl .c files), HAL, FreeRTOS |

Effect:
- `#include "io/io_spi.h"` from `app/cm4/state_estimation_task.c` → build error (header not on the include path of `app_cm4`'s transitive deps).
- `#include "io/io_spi.h"` from `dev/imu_bmi088/src/imu_bmi088.c` → OK (`io` is PRIVATE-linked).
- The executable transitively gets all of IO via its app + dev deps, plus directly via its own Bsp/Io impl .c sources. Nobody else sees the whole pile.

### Move 7 — Four explicit init phases, owned bottom-up

```c
int main(void) {
    SystemInit();              /* HW boot, clock, MPU */
    io_init_cm4();             /* IO layer: bring up spi_queue/uart/exti/etc. */
    dev_init_cm4();            /* DEV layer: each driver self-inits */
    app_init_cm4();            /* APP layer: create tasks, wire notifies */
    app_start_kernel();        /* never returns */
}
```

`dev_init_cm4()` is just:
```c
void dev_init_cm4(void) {
    imu_bmi088_init();
    imu_icm40609_init();
    baro_ms5611_init();
    gps_nmea_init();
    radio_rfd900_init();
}
```
…and the CM7 equivalent inits its actuators. No app code knows about init ordering between drivers.

`app_start_kernel()` is the scheduler entry; on H747 it's `vTaskStartScheduler()`; on SIL it's `pthread_join` over the simulated thread pool.

### Move 8 — `io_status_t` instead of `bool` returns

Every IO entry point returns a typed status:
```c
typedef enum {
    IO_OK = 0,
    IO_ERR_BUSY,
    IO_ERR_TIMEOUT,
    IO_ERR_NACK,
    IO_ERR_BUS,
    IO_ERR_NO_DEVICE,
    IO_ERR_PARAM,
} io_status_t;
```

DEV drivers can react meaningfully (retry on `BUSY`, mark sensor offline after N `BUS`, etc.). Initial conversion is mechanical (`bool` → `IO_OK`).

---

## Implementation order

| # | Move | Risk | Effort |
|---|---|---|---|
| 1 | Privatise globals (Move 1) | very low | 30 min |
| 2 | Rename `bsp` → `io`, `drivers` → `dev` (Move 4) | very low — pure rename | 1 h |
| 3 | Four-phase init (Move 7) | low | 30 min |
| 4 | Split IO surfaces (Move 5) + CMake visibility (Move 6) | low — mechanical | 1 h |
| 5 | Drop driver config structs; symbolic IO binding (Move 3) | medium — touches every driver | 1.5 h |
| 6 | Opaque DEV singletons (Move 2) | medium — touches every driver header | 1 h |
| 7 | `io_status_t` typed returns (Move 8) | low — touches every IO call site, but mechanical | 1 h |

Total: ~6 hours, fully reversible at each step.

---

## Definition of done

- `grep -rn "^[A-Za-z_].* [a-zA-Z_][a-zA-Z_0-9]* *= " app/ libs/dev/ libs/io/` returns only `static` definitions and `const`-table initialisers.
- `app/` translation units include nothing under `io/` — only `io_sys/`, `app/`, `dev/`, `controls/`, `state_estimation/`, `log_records/`. Enforced by CMake (Move 6) and verified by a grep at PR time.
- DEV driver headers contain only forward-declared opaque types + APIs. No struct field is externally visible.
- Renaming or remapping `IO_SPI_BMI088_ACC` in `io/h747/cm4/io_spi_resources.c` does not require any edit under `libs/dev/`.
- An empty `io/sil/` stub directory exists with placeholder symbol definitions; an HD build (host-defined `IO_TARGET_SIL`) of `dev/` + `app/` links successfully against the stub. This is the lowest-cost SIL-readiness gate.
- `cd libs/controls/tests && ./build/test_controls` → 93 / 0 / 0.
- `cd libs/state_estimation/tests && ./build/test_state_estimation` → 32 / 0 / 0.

---

## Explicit non-goals

- No introduction of C++.
- No RTOS abstraction layer above FreeRTOS for now (will reconsider when SIL lands).
- No code generation, no DSL, no per-board config files driven from JSON/YAML.
- No change to `state_exchange` / `log_service` interfaces.
- Not in scope: actually filling in BMI088 / ICM-40609 / MS5611 init bodies, DShot TIM+DMA wiring, linker `.shared` section, MPU config. Those land independently after the hardening is in place.

---

## Why this is better than v1

- **Simpler model**: no app-side "binding" step. The board is a fixed thing; the driver knows it.
- **Easier to read**: looking at `dev/imu_bmi088/src/imu_bmi088.c` tells you everything about how the BMI088 is wired, with no jumping through app code.
- **SIL story sharper**: the substitution boundary is exactly the IO layer's resource-symbol table. Drivers don't need to know SIL exists.
- **Honest about reality**: drivers were always going to know their wiring (you can't write a sensible BMI088 register sequence without knowing which CS to assert). v1 tried to pretend otherwise via abstraction. v2 names the truth.

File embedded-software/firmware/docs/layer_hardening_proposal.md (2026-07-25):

# Proposal: Layer Hardening + Encapsulation (IO / Dev / App)

> **SUPERSEDED** by [architecture_layers.md](architecture_layers.md). The v2
> doc rejects this proposal's "app does the BSP wiring" pattern in favour of
> self-contained device drivers. Kept here as historical context only.

**Status:** superseded
**Author:** Benedikt Howard (drafted with Claude)
**Date:** 2026-05-16

---

## Motivation

The transport-BSP / driver / app split is in place but soft. Today:

- A few **cross-TU globals** still exist (`g_servos`, `g_escs` in [app_init_cm7.c](../app/cm7/app_init_cm7.c)) where module-local statics + getters would be cleaner.
- **Driver-internal data lives in public headers** (e.g. the full `imu_bmi088_t` struct fields are visible to anyone who includes [imu_bmi088.h](../libs/drivers/imu_bmi088/include/drivers/imu_bmi088.h)).
- **The app pulls BSP transport headers** in places it shouldn't (`controls_task.c` includes `bsp/bsp_timestamp.h` — fine for system services, but the same pattern would let it reach into `bsp_spi.h`).
- **The driver knows BSP logical IDs** (`imu_bmi088_init` takes `BSP_SPI_BMI088_ACC` etc.). The driver shouldn't know which slot it's plugged into.
- **CMake link visibility is permissive** — most libraries are linked `PUBLIC`, so a top-of-tree consumer transitively gets the whole world.

These are not bugs today, but they are exactly the kinds of softness that turns into a tangle once the codebase doubles in size. Hardening them now is cheap; hardening them later is not.

This document proposes a small set of concrete moves.

---

## Goals

1. No object visible outside its translation unit unless it has to be.
2. Every layer's headers expose **what** that layer offers, not **how** it works.
3. App code can call into device drivers and a small "system services" subset of the BSP, but cannot reach transport (SPI / UART / EXTI / DShot / SD).
4. Drivers can call BSP but have no knowledge of which physical peripheral they are bound to.
5. CMake enforces (3) and (4): linking the app target should not transitively expose transport symbols.

Non-goals: no source reshuffling beyond what's required, no behavioural change.

---

## Move 1 — Replace cross-TU globals with module-local statics + getters

### Current

```c
/* app/cm7/app_init_cm7.c */
servo_feetech_t g_servos;   /* visible to anyone with `extern` */
esc_dshot_t     g_escs;
```

Anything in any TU can `extern servo_feetech_t g_servos;` and bypass init contracts.

### Proposed

Move device singletons into an `actuators_init.{h,c}` mirror of [sensors_init.h](../app/include/app/sensors_init.h). The actuator structs are `static` inside the .c; the header exposes only an `actuators_t` view-struct of pointers, returned by `actuators_handles()`.

```c
/* app/cm7/actuators_init.c */
static servo_feetech_t s_servos;
static esc_dshot_t     s_escs;
static actuators_t     s_handles;

void actuators_init(void) { /* configure both, populate s_handles */ }
const actuators_t *actuators_handles(void) { return &s_handles; }
```

```c
/* app/cm7/controls_task.c */
const actuators_t *act = actuators_handles();
servo_feetech_set_pair_degrees(act->servos, deg_x, deg_y);
esc_dshot_set_throttle(act->escs, throttle);
```

Apply the same pattern to **every** non-static module-level object. Concretely:

| File | Today | After |
|---|---|---|
| `app/cm7/app_init_cm7.c` | `g_servos`, `g_escs` global | `static`, exposed via new `actuators_init.h` |
| `flight_controller/CM4/Bsp/bsp_spi.c` | `s_q[]`, `s_q_init[]`, `s_devs[]` | already static — leave alone |
| `flight_controller/CM4/Bsp/bsp_uart.c` | `s_uart[]`, `s_map[]` | already static |
| `flight_controller/CM7/Bsp/bsp_dshot_tim.c` | `s_dma_buf`, `s_busy` | already static |
| any other `extern`s | none found | n/a |

The point of doing the audit is to make "no cross-TU globals" a rule we enforce, not an accident.

---

## Move 2 — Opaque driver handles

### Current

```c
/* libs/drivers/imu_bmi088/include/drivers/imu_bmi088.h */
typedef struct {
    bmi088_accel_t accel_dev;
    bmi088_gyro_t  gyro_dev;
    /* ... full ring buffer, notify target, etc. */
} imu_bmi088_t;
```

A caller can read or write any field. Drive-by includes pull the full type and slow incremental builds.

### Proposed

Driver headers expose only a forward-declared opaque type plus the public API. The struct definition lives in the .c. The caller no longer allocates one — it asks the driver for one.

```c
/* libs/drivers/imu_bmi088/include/drivers/imu_bmi088.h */
typedef struct imu_bmi088 imu_bmi088_t;        /* opaque */

bool                imu_bmi088_init(const imu_bmi088_cfg_t *cfg);
const imu_bmi088_t *imu_bmi088_get(void);
size_t              imu_bmi088_drain(const imu_bmi088_t *d, imu_sample_t *out, size_t max);
```

The driver owns its own storage (`static imu_bmi088_t s_singleton;` in the .c). `imu_bmi088_get()` returns `&s_singleton` after init, NULL before. Single instance per driver is the only sane model on this MCU anyway — one BMI088, one ICM-40609, etc. — so the singleton restriction is honest.

Apply uniformly to:
- `imu_bmi088`, `imu_icm40609`
- `baro_ms5611`
- `gps_nmea`, `radio_rfd900`
- `servo_feetech`, `esc_dshot`

`sensors_t` and `actuators_t` view-structs hold the opaque pointers returned by each driver's `*_get()`.

**Tradeoff:** no `xTaskCreateStatic`-style "you allocate the storage" pattern. Acceptable because the storage is bounded and small (a handful of structs total).

---

## Move 3 — Drop logical BSP IDs from driver configs

### Current

```c
imu_bmi088_init(&d, &(imu_bmi088_cfg_t){
    .acc_dev   = BSP_SPI_BMI088_ACC,
    .gyro_dev  = BSP_SPI_BMI088_GYRO,
    .acc_int   = BSP_EXTI_BMI088_ACC_INT1,
    .gyro_int  = BSP_EXTI_BMI088_GYRO_INT1,
});
```

The driver header forces the caller — and indirectly the driver source — to know which logical BSP slot the device is on. That's a leak: the BSP enum is target-specific. A SIL build would have to define the same enum values to satisfy the driver's signature.

### Proposed

Wrap the (SPI device, CS, EXTI) tuple into a BSP-provided **session handle** that the driver takes opaquely:

```c
/* libs/bsp/include/bsp/bsp_spi.h */
typedef struct bsp_spi_session bsp_spi_session_t;

/* Returned by the BSP for a logical device. The driver carries the pointer;
 * the BSP knows what's behind it. */
const bsp_spi_session_t *bsp_spi_session(bsp_spi_dev_t dev);
```

The driver `init` then accepts session handles, not enum values:

```c
typedef struct {
    const bsp_spi_session_t  *acc;
    const bsp_spi_session_t  *gyro;
    const bsp_exti_session_t *acc_int;
    const bsp_exti_session_t *gyro_int;
} imu_bmi088_cfg_t;
```

The app (in `sensors_init.c`) does the binding once:

```c
imu_bmi088_init(&(imu_bmi088_cfg_t){
    .acc      = bsp_spi_session(BSP_SPI_BMI088_ACC),
    .gyro     = bsp_spi_session(BSP_SPI_BMI088_GYRO),
    .acc_int  = bsp_exti_session(BSP_EXTI_BMI088_ACC_INT1),
    .gyro_int = bsp_exti_session(BSP_EXTI_BMI088_GYRO_INT1),
});
```

The driver source uses `bsp_spi_submit_to(session, &xfer)` etc. — no enum. SIL provides its own enum + sessions; the driver is untouched.

Cost: one extra hop (BSP enum → session) per call site. The session lookup is `O(1)` table indexing.

---

## Move 4 — Tier the BSP into "system services" vs "transport"

App code legitimately wants:
- A monotonic clock (`bsp_timestamp_us`)
- Inter-core signalling (`bsp_intercore_*` — though arguably the app should use `state_exchange` and `log_service`, not raw HSEM)
- Status LEDs

App code does **not** want:
- `bsp_spi_*`, `bsp_uart_*`, `bsp_exti_*`, `bsp_dshot_*`, `bsp_sd_*` — those are the driver layer's concern.

### Proposed split

Two interface libraries instead of one:

```
libs/
├── bsp/                    # transport — internal to driver builds
│   └── include/bsp/
│       ├── bsp_spi.h
│       ├── bsp_uart.h
│       ├── bsp_exti.h
│       ├── bsp_dshot.h
│       ├── bsp_sd.h
│       └── bsp_types.h
└── bsp_sys/                # system services — visible to app
    └── include/bsp_sys/
        ├── bsp_timestamp.h
        ├── bsp_intercore.h
        ├── bsp_status_led.h
        └── bsp_init.h        # bsp_kernel_start lives here
```

The two halves still get implemented in the same per-core `flight_controller/CM{4,7}/Bsp/` directory — this is purely a header-namespace split.

CMake then links:
- `drivers/*` PRIVATE → `bsp` + `bsp_sys`
- `app_*` PRIVATE → `bsp_sys` only

Result: a `#include "bsp/bsp_spi.h"` from `app/cm4/controls_task.c` becomes a build error (header not on include path).

---

## Move 5 — Tighten CMake link visibility

Today every `target_link_libraries(... PUBLIC)` transitively re-exports the linked lib. That makes app targets accidentally see every BSP header.

### Proposed rule

| Producer | PUBLIC linkage to | PRIVATE linkage to |
|---|---|---|
| `libs/bsp` (interface) | — (header-only) | — |
| `libs/bsp_sys` (interface) | — (header-only) | — |
| `libs/spi_queue` etc. | `stm32cubemx` | — |
| `libs/drivers/X` | `bsp_sys` | `bsp`, `libs/sensors/*`, `libs/spi_queue`, `libs/uart_dma_cm` |
| `libs/app_shared` | `bsp_sys`, `state_estimation`, etc. | — |
| `libs/app_cm4` | `app_shared`, `bsp_sys`, `drivers/*` | — |
| per-core executable | (everything via app_cmX) | `bsp` (only for the Bsp/ impl .c files), HAL, FreeRTOS |

The takeaway: the **executable** is the one place that sees both halves of the BSP, because it compiles the impl files. Nobody else has both.

---

## Move 6 — Split `bsp_init` from `drivers_init` from `app_init`

### Current

`app_init_cm4()` instantiates drivers **and** creates tasks. They're the same step.

### Proposed

Three phases, three functions, three layers:

```c
/* main.c */
SystemInit();
bsp_init_cm4();        // hardware → ready
drivers_init_cm4();    // sensors_init + log_service init
app_init_cm4();        // create FreeRTOS tasks
bsp_kernel_start();    // never returns
```

`drivers_init_cm4()` lives in `app/cm4/drivers_init_cm4.c` (or directly in `sensors_init.c`); `app_init_cm4()` only does task creation + cross-task wiring. The phases also make initialisation order explicit, which we'll appreciate the first time a driver init has to spin on something.

The reverse on shutdown is symmetric (not relevant on this MCU but is for SIL).

---

## Move 7 — Replace `bool` returns with a `bsp_status_t`

Drivers can't tell *why* a `bsp_spi_submit` failed today — queue full, bus busy, peripheral fault, all collapse to `false`. A typed status lets the driver:

- Retry on transient busy/queue-full
- Escalate fault states to mission manager
- Mark a sensor as offline after N consecutive bus errors

```c
typedef enum {
    BSP_OK = 0,
    BSP_ERR_BUSY,
    BSP_ERR_TIMEOUT,
    BSP_ERR_NACK,
    BSP_ERR_BUS,
    BSP_ERR_NO_DEVICE,
    BSP_ERR_PARAM,
} bsp_status_t;
```

Every BSP entry point returns `bsp_status_t` instead of `bool`. Existing `bool`-returning drivers either propagate or collapse.

---

## What this is *not*

- **Not a redesign**: every interface that exists today still exists; we are tightening the contracts and renaming a few.
- **Not adding RTOS abstractions**: tasks, semaphores, notifications stay FreeRTOS-typed for now. (A future SIL pass will deal with this.)
- **Not introducing C++ niceties**: no inheritance, no templates, no smart pointers.

---

## Implementation order (suggested)

1. **Move 1** (globals → statics) — pure-mechanical, no API changes. ~30 min.
2. **Move 6** (init phase split) — adds clarity, no behavioural change. ~30 min.
3. **Move 4** + **Move 5** (bsp_sys split + CMake visibility) — biggest semantic win; touches every CMakeLists.txt but is mechanical. ~1 h.
4. **Move 2** (opaque handles) — touches every driver header but is the same edit each time. ~1 h.
5. **Move 7** (`bsp_status_t`) — touch every BSP signature; drivers initially just `if (... != BSP_OK)`. ~1 h.
6. **Move 3** (sessions) — most invasive; defer until #2 lands. ~2 h.

Total: roughly half a day of careful edits, no functional risk.

---

## Definition of done

- `grep -rn "^[a-zA-Z_].* g_" app/ libs/drivers/` returns nothing.
- `app/` includes no header under `bsp/` (only `bsp_sys/`).
- Driver headers expose only a forward-declared struct + APIs; struct fields are not externally visible.
- Removing `BSP_SPI_BMI088_ACC` from `bsp_spi.h` (i.e., renaming the enum value) does not require touching any file under `libs/drivers/`.
- `cd libs/controls/tests && ./build/test_controls` still: 93 / 0 / 0.
- `cd libs/state_estimation/tests && ./build/test_state_estimation` still: 32 / 0 / 0.

---

## What still has to land outside this proposal (recap)

These are tracked separately and are not in scope here:

- main.c on each core calling `bsp_init → drivers_init → app_init → bsp_kernel_start`.
- IRQ glue in `stm32h7xx_it.c` for UART CM and HSEM.
- Linker-script `.shared` section in SRAM4, exported `__shared_region_start__`.
- MPU configuration for CM7 D-cache + SRAM4 non-cacheable region.
- Actually filling in the device init sequences (BMI088, ICM-40609, MS5611) and the actuator TIM/DMA wiring (DShot).
- Porting the task bodies from `depracated/`.

The hardening above is a prerequisite for those steps to land *clean*, not a substitute for them.

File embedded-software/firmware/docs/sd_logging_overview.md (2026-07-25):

# SD Card Logging

> **Heads-up.** Describes the deprecated H5 implementation. The new H747
> design moves the SD writer to CM4 (`io/h747/CM4/io_sd.c`) behind the
> `io_sd_*` API, and consolidates `log_service` / `log_writer` into
> `app/cm4/sd_log_task.c` (currently a stub). The schema layer
> (`lib/log_records/`) is unchanged.

> **Status:** In development. The logger streams records to the SD card, but recovery tooling and mission-critical validation are still ongoing.

## Goals

Simplify post-flight analysis by capturing structured telemetry directly to an SD card without needing an external PC. Records follow the shared schema in `lib/log_records/include/log_records/log_records.h`, so firmware and host tools stay in sync.

## Architecture

1. **Detection & init** (`Core/Src/main.c`):
   * `MX_SDMMC1_SD_Init()` only runs when the card-detect GPIO reports a card present.
   * Init configures the SDMMC for 4-bit transfers but intentionally divides the bus clock (`ClockDiv = 4`, ~12 MHz) to keep CRC margins healthy on our board routing; once the card responds, the controller’s internal DMA (IDMA) and NVIC path are enabled so block writes run without CPU copies.
   * `g_sd_card_initialized` reflects whether the card is ready for logging.

2. **Log writer** (`Core/Src/SD_logging/log_writer.c`):
   * Double-buffered 512-byte blocks; each buffer fills with framed records and is flushed via `HAL_SD_WriteBlocks_DMA`.
   * Frames consist of a small header (`magic`, `type`, `payload length`, `CRC16`) followed by the payload, matching the structs in `log_records.h`.
   * A FreeRTOS mutex guards buffer access so any task can enqueue records safely.
   * DMA completion ISR releases a semaphore, allowing the next buffer to be written without blocking the mission manager; errors propagate through `HAL_SD_ErrorCallback`, so the mission tasks immediately stop logging if the card reports CRC/timeouts.
   * Before logging starts, the first ~4 MB of the card are erased to guarantee stale data from earlier flights is cleared.

3. **Log service use in tasks**:
   * Mission manager calls `log_service_try_init`, `log_service_log_event` (E-STOP + flight-state transitions), and `log_service_periodic_flush`. Radio logging hooks will land here as the parser matures.
   * As soon as the SD backend is ready, mission manager emits a `flight_header` record containing a per-flight magic value; decoders can lock onto the newest header to ignore historical data.
   * The state-estimation task logs accelerometer, gyro, and barometer samples after dequeuing them, and also logs each fused state snapshot with the latest flight state. All of this happens in task context.
   * `log_service` (`Core/Src/SD_logging/log_service.c`) hides the framing, CRC, and DMA flush cadence; tasks simply pass physical units (m/s², rad/s, centi-units).

## Host tooling

* `tools/logging/generate_log_schema.py` parses `log_records.h` and produces `tools/logging/log_schema.py`.
* `tools/SD/decode_log.py` walks a raw sector dump, validates CRCs, and emits newline-delimited JSON; by default it expects `tools/SD/bin/log_dump.bin` and writes `tools/SD/logs/flight.jsonl`, so `python tools/SD/decode_log.py` is enough after copying your dump there.
  * Override paths via `python tools/SD/decode_log.py /tmp/dump.bin --output /tmp/flight.jsonl`.
  * Pass `--latest-flight` to automatically focus on the newest flight header, or `--flight-magic 0xDEADBEEF` to pin to a specific run.
* Ground scripts can import the shared schema (see above) to build richer tooling if the stock decoder needs extension.

## Extracting a Raw SD Dump

**macOS / Linux**

1. Insert the SD card and identify the device node (e.g., `diskutil list` on macOS or `lsblk` on Linux).
2. Unmount/open the device so nothing else is writing: `diskutil unmountDisk /dev/disk4` (macOS) or `sudo umount /dev/sdX1` (Linux).
3. Use `dd` against the *raw* device to copy either the first few megabytes or the full card. Example (first 4 MB, matching the firmware’s preflight erase window):
   ```
   sudo dd if=/dev/rdisk4s1 of=$HOME/ubc_rocket/ulysses/tools/SD/logs/log_dump.bin bs=1m count=4
   ```
   Increase `count=` or drop it entirely if you want the full contents. Always point `of=` somewhere inside your user account so permissions stay friendly.

**Windows**

1. Open Disk Management (`diskmgmt.msc`) and note the SD card’s physical drive number (e.g., `PhysicalDrive2`). Make sure the volume is dismounted.
2. From an elevated PowerShell or Command Prompt, run a Windows build of `dd` or use Win32DiskImager. Example with `dd` (from Cygwin/MSYS/GnuWin32):
   ```
   dd if=\\.\PhysicalDrive2 of=C:\logs\log_dump.bin bs=1M --progress
   ```
   Win32DiskImager users can click **Read** to save the entire card into `log_dump.bin`.
3. Move `log_dump.bin` into `tools/SD/logs/` and run `python tools/SD/decode_log.py --latest-flight` to get `flight.jsonl`.

## Small-print / Known limitations

* **WIP:** No filesystem. Data is appended as raw sectors, so you’ll need a custom decoder script to interpret the log.
* **Power loss:** The logger is append-only; unflushed data in the active buffer is lost if power drops. Flush frequency can be tuned in mission manager.
* **Card compatibility:** Initialization has been tested with standard SDHC and some UHS-I cards, but high-speed tuning, wear-level behaviour, and long-duration stress tests remain.
* **Tooling gap:** Scripts to parse the binary log into CSV/plots are planned but not included yet.

Despite the “WIP” status, the framework is designed so that once tooling is ready, the firmware can log arbitrarily complex records without further schema drift.

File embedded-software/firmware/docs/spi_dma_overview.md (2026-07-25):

# SPI + DMA Sensor Bus Overview

> **Heads-up.** This document describes the deprecated H5 implementation
> (paths under `depracated/ulysses-flight-controller/`). The current H747
> firmware uses the same patterns but in the new `io/io_spi_queue/` +
> `io/h747/CM4/io_spi.c` layout. See
> [architecture_layers.md](architecture_layers.md) for the new layering.

This note explains how the flight computer shares a single SPI bus among multiple sensors by combining a DMA-powered transfer engine with a small job queue. It is written for a general audience, so every term is defined as it appears.

## Why this architecture exists

The BMI088 accelerometer, BMI088 gyro, and MS5611 barometer all speak **SPI** (Serial Peripheral Interface), a protocol where a master toggles a **chip-select (CS)** line to talk to one slave at a time. Only one transfer can be “on the wire” at any given instant. Polling each device inside a loop would waste CPU cycles and risks missing samples, so Ulysses uses:

1. **Data-ready interrupts** (BMI088 INT1, gyro INT, baro timing) so sensors tell us exactly when a sample is available (`Core/Src/interrupts.c`).
2. A **job queue** that records “who wants the bus next” in FIFO order (`Core/Src/spi_drivers/SPI_queue.c`).
3. **DMA (Direct Memory Access)** so the SPI peripheral moves bytes to/from memory without CPU involvement, freeing the Cortex‑M33 to run navigation tasks.

The combination guarantees lossless acquisition even when multiple sensors assert their data-ready pins at nearly the same moment.

## Glossary

| Term | Definition |
| --- | --- |
| **SPI transfer** | A burst of clocked bits where the MCU simultaneously transmits (`MOSI`) and/or receives (`MISO`) data. All transfers specify a CS pin so the correct sensor listens. |
| **DMA** | Hardware that copies memory for a peripheral without the CPU touching every byte. The STM32H5 SPI block can request DMA for transmit, receive, or both. |
| **Job** | One queued SPI transaction described by `spi_job_t` (CS port/pin, transmit buffer, length, transfer type, completion callback, timestamp, and sensor identifier). |
| **Job queue** | A circular buffer (`spi_job_queue_t`) that stores pending jobs plus bookkeeping (head/tail pointers, “bus busy” flag, staging buffer for RX data). |
| **Data-ready interrupt** | A GPIO interrupt that fires when a sensor asserts “new data available.” In `HAL_GPIO_EXTI_Rising_Callback` these interrupts dispatch to `bmi088_accel_interrupt()` or `bmi088_gyro_interrupt()` to enqueue SPI work. |

## End-to-end flow

1. **Interrupt fires**  
   - The BMI088 accelerometer pulses `BMI_ACC_INT_1_Pin`. HAL routes this to `HAL_GPIO_EXTI_Rising_Callback` in `Core/Src/interrupts.c`.  
   - We check `bmi088_accel_ready` and call `bmi088_accel_interrupt()`.

2. **Job creation** (`Core/Src/spi_drivers/bmi088_accel_device.c`)  
   - The interrupt handler populates a `spi_job_t` with:
     * CS port/pin for the accelerometer.
     * A transmit buffer built by `bmi088_accel_build_read(...)`, which contains the SPI read command and dummy bytes.
     * The sample timestamp (`timestamp_us()`), so we can reconstruct when the sensor captured the data.
     * The completion callback `bmi088_accel_done`, which parses the returned bytes into physical acceleration and pushes it into the accelerometer sample ring via `bmi088_acc_sample_q_push`.
   - The job is submitted via `spi_submit_job(job, &jobq_spi_2)` (job queue bound to SPI2).

3. **Queue arbitration** (`Core/Src/spi_drivers/SPI_queue.c`)  
   - `spi_submit_job` briefly disables interrupts, checks whether the bus is idle, and either:
     * Starts the job immediately (`start_job`), or
     * Copies it into the circular queue if the bus is already busy.
   - This guarantees only one DMA transfer is active at a time, preventing chip-select collisions.

4. **DMA transfer**  
   - `start_job` asserts the sensor’s CS line, unlocks the HAL SPI handle (because HAL leaves it locked inside IRQ context), and starts the appropriate DMA mode (`HAL_SPI_Transmit_DMA`, `_Receive_DMA`, or `_TransmitReceive_DMA`).  
   - DMA pushes bytes directly between memory and the SPI peripheral while the CPU continues running FreeRTOS tasks.

5. **Completion ISR**  
   - When DMA finishes, HAL calls `HAL_SPI_*CpltCallback`, which funnels into `spi_dma_complete_common`.  
   - We deassert CS, invoke the job’s `done` callback (still inside ISR context), and parse the sensor payload.  
   - The job queue is checked for pending work; if another job exists, `start_job` is called immediately to keep the bus busy with virtually no gap.

6. **Data ready again**  
   - The sensor queues the next transfer the next time it asserts the data-ready pin, and the process repeats.

## Why use DMA + job queue?

* **Deterministic timing:** Data-ready interrupts mean the MCU responds right when the sensor has new data, reducing latency compared to polling.
* **Bus safety:** The queue serializes access so two devices never drive the SPI lines simultaneously, which could otherwise corrupt readings.
* **CPU efficiency:** DMA offloads the byte shoveling. The CPU only handles small control steps (queueing jobs, parsing results) which is critical during the high-rate 1 kHz sensor fusion loop.
* **ISR-friendly completion:** Each job records a callback that is safe to run inside the DMA completion ISR. That callback performs lightweight parsing and drops samples into lock-free SPSC ring buffers (generated by `SPSC_RING_DECLARE` from `libs/collections/`). Higher-level tasks (e.g., `state_estimation_task_start`) pull from those rings without blocking the interrupt path.

## Interplay with the rest of the system

* `Core/Src/tasks/state_estimation.c` pulls fused samples from the sensor rings, producing a navigation state vector consumed by mission logic.
* `Core/Src/interrupts.c` ties the physical GPIO interrupts into the SPI job submission functions.
* `Core/Src/spi_drivers/*` encapsulate device-specific details (how to build read commands, how to parse payloads), keeping the queue generic.

Together these pieces form a responsive, low-overhead sensor acquisition path suitable for rockets, UAVs, or any embedded application where multiple SPI sensors must coexist without missing data.

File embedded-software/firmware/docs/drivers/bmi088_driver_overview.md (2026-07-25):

# BMI088 IMU Driver Overview

> **Heads-up.** Describes the deprecated H5 driver. The new H747 driver
> lives at `dev/imu_bmi088/` and reuses the same `lib/sensors/bmi088_*`
> protocol helpers above the `io_spi_*` transport.

This note documents how the Ulysses firmware configures and samples the Bosch BMI088 inertial measurement unit (IMU), which integrates a three-axis accelerometer and a three-axis gyroscope. It covers the initialization sequence, data-ready flow, SPI job wiring, and how raw samples are converted into physical units.

## Accelerometer path

### Initialization sequence

`Core/Src/spi_drivers/bmi088_accel_device.c` performs a deterministic configuration ordered as follows (matching the Bosch datasheet requirements):

1. **Soft reset** – `bmi088_accel_build_softreset` writes `0xB6` into `ACC_SOFTRESET`, guaranteeing the device starts from a known state.
2. **Chip ID validation** – read from `ACC_CHIP_ID` and compare against `0x1E`. If the ID differs, the driver aborts with error code `1`.
3. **Power-up** – two writes of `bmi088_accel_build_power_conf` ensure `Pwr_Conf` exits suspend and `Pwr_Ctrl` enables the accelerometer core (expecting `Pwr_Ctrl = 0x04`). Failure returns error codes `2` or `3`.
4. **Range** – `bmi088_accel_build_range(BMI088_ACC_RANGE_3G, …)` selects ±3 g and sets the internal scale factor (mg/LSB) used later during parsing.
5. **Bandwidth / ODR** – `bmi088_accel_build_odr_bw(BMI088_ACC_ODR_800_HZ, BMI088_ACC_BWP_NORMAL, …)` requests an 800 Hz data rate with normal bandwidth, balancing latency and noise.
6. **INT1 routing** – `bmi088_accel_build_int_pin_conf` configures INT1 as push-pull, active-high, non-latching; `bmi088_accel_build_int_event_map` maps the DATA_READY event onto that pin.
7. **Sanity checks** – multiple reads of `STATUS`, `ACC_CONF`, `ACC_RANGE` confirm the configuration stuck, validating that bit 7 of STATUS (data ready) toggles.

Each SPI transaction toggles the accelerometer’s chip-select (`BMI_ACC_CS`) manually with small inter-transfer delays (`delay_us`) to meet datasheet timing. Initialization returns `0` on success, or a small non-zero code indicating where validation failed.

### Data-ready and job submission

* The BMI088 accelerometer asserts INT1 every time a new sample is available. This pin is wired to `BMI_ACC_INT_1_Pin`, which triggers the EXTI path handled in `Core/Src/interrupts.c`.
* In `HAL_GPIO_EXTI_Rising_Callback`, the code checks `bmi088_accel_ready` and calls `bmi088_accel_interrupt()`.
* `bmi088_accel_interrupt()` constructs a `spi_job_t` with:
  - `cs_port = BMI_ACC_Chip_Select_GPIO_Port`, `cs_pin = BMI_ACC_Chip_Select_Pin`.
  - `len = bmi088_accel_build_read(BMI088_ACC_READ_DATA_XYZ, job.tx)` to queue a six-byte XYZ read plus command overhead.
  - `t_sample = timestamp_us()` so the sample retains timing metadata.
  - `type = SPI_XFER_TXRX` because SPI needs dummy clocks to receive data.
  - `done = bmi088_accel_done`, which parses received bytes and enqueues the decoded vector.
  - `sensor = SENSOR_ID_ACCEL` for bookkeeping.
* The job is submitted to the shared queue `jobq_spi_2` via `spi_submit_job`. From here the generic SPI + DMA machinery described in the previous document executes the transfer, and the completion callback runs inside the DMA ISR.

### Sample parsing and buffering

`bmi088_accel_done` receives the RX buffer (starting at byte 2 because the first two bytes are command/dummy). It uses `bmi088_accel_parse_data_xyz` to translate raw 16-bit counts into m/s² values by applying the scale factor saved during initialization. The callback then sets `sample.t_us = job->t_sample` and pushes the struct into the accelerometer sample ring via `bmi088_acc_sample_q_push`, using the generic SPSC ring buffer defined in `libs/sensors/include/sensors/bmi088_accel.h` (backed by `SPSC_RING_DECLARE` from `libs/collections/include/collections/spsc_ring.h`).

The ring buffer feeds `state_estimation_task_start`, which drains up to 32 samples per loop iteration for fusion.

## Gyroscope path

The gyro follows the same pattern but with gyro-specific registers and conversion factors.

### Initialization highlights

Located in `Core/Src/spi_drivers/bmi088_gyro_device.c`:

1. **Soft reset & chip ID** – ensures the device responds with `BMI088_GYRO_CHIP_ID_VALUE`.
2. **Power enable** – sets `GYRO_PWR` registers to normal operating mode.
3. **Output data rate / bandwidth** – configured via `bmi088_gyro_build_range_and_bw` (e.g., 2000 °/s, 2000 Hz bandwidth, depending on mission requirements).
4. **Interrupt routing** – INT3/INT4 pins are configured similarly to the accelerometer so data-ready events produce GPIO interrupts.

Each step mirrors the accelerometer flow so both sensors are ready before data collection begins.

### Interrupt + job submission

* The gyro’s data-ready pin maps to `BMI_GYRO_INT_1_Pin`. When `HAL_GPIO_EXTI_Rising_Callback` sees this pin and `bmi088_gyro_ready` is true, it calls `bmi088_gyro_interrupt()`.
* That function builds a `spi_job_t` containing a FIFO read or direct XYZ read depending on configuration. The sample timestamp and completion callback (`bmi088_gyro_done`) are populated in the same manner as the accelerometer path.
* Jobs are submitted to the same `jobq_spi_2` queue, meaning accelerometer and gyro requests are arbitrated in arrival order.

### Parsing and buffering

`bmi088_gyro_done` calls `bmi088_gyro_parse_data_xyz` (or FIFO parser) to convert raw counts into rad/s values using the range-dependent LSB scale. Parsed samples are pushed into the gyro sample ring via `bmi088_gyro_sample_q_push` for later use. The state-estimation task consumes these alongside the accelerometer and barometer samples to build the fused attitude solution.

## Failure handling and readiness flags

Both drivers expose `bmi088_accel_ready` / `bmi088_gyro_ready` flags that gate the EXTI callback. Initialization sets these flags true only if setup succeeded. If initialization fails (chip ID mismatch, power state incorrect, etc.), the flags remain false, preventing noisy interrupts from scheduling SPI jobs that would inevitably fail. This guard keeps the SPI queue from filling with invalid work and leaves room for future retries or fault reporting.

## How this ties into mission logic

* The accelerometer and gyro sample rings feed `state_exchange` and the `state_estimation` task, which compute vehicle attitude and rates.
* Mission manager logic (e.g., the orientation-based e-stop) relies on this fused state to decide whether to abort.
* The debug UART now prints a subset of recent accelerometer/gyro samples, leveraging the same ring buffers, making it easier to validate driver behaviour.

With these drivers, the BMI088 IMU delivers high-rate inertial data with precise timestamps, consistent configuration, and minimal CPU overhead thanks to the shared SPI DMA job queue.

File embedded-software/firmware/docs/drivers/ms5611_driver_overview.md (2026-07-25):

# MS5611 Barometer Driver Overview

> **Heads-up.** Describes the deprecated H5 driver. The new H747 driver
> lives at `dev/baro_ms5611/` and uses the same `lib/sensors/ms5611_baro.*`
> protocol helpers behind the `io_spi_xfer_blocking` API.

The MS5611 is a high-resolution barometric pressure sensor used to estimate altitude. Unlike the BMI088, it provides pressure and temperature through two ADC conversions (D1 and D2). This document tracks how the firmware initializes the baro, schedules conversions, reads results over SPI + DMA, and feeds samples into the fusion pipeline.

## Initialization sequence

`Core/Src/spi_drivers/ms5611_device.c` contains `ms5611_init`, which is called from `ms5611_poller_init`. The key steps are:

1. **Reset** – `ms5611_build_reset` constructs the `0x1E` command, which is sent to the sensor with chip select toggled manually.
2. **PROM read** – The MS5611 stores calibration coefficients `C1..C6` (and CRC) in its PROM. The driver loops over all eight addresses via `ms5611_build_prom_read`, reading each 16-bit word and parsing it with `ms5611_parse_prom_word`. The results populate `ms5611_t::C[]`.
3. **CRC check** – `ms5611_check_crc` validates the PROM contents. If the CRC fails, initialization returns error code `2`.
4. **Ring buffer reset** – the `ms5611_sample_q_t` ring buffer (generated by `SPSC_RING_DECLARE` in `libs/collections/include/collections/spsc_ring.h`) head and tail pointers are zeroed so consumers start from a clean queue.
5. **Polling state** – `ms5611_poller_init` stores the SPI handle, CS pin, desired oversampling ratio (OSR), and output data rate (ODR). It calls `ms5611_poller_set_rate` to convert OSR into the required conversion delay (microseconds) and the interval between conversions.

If initialization succeeds, the poller is ready to orchestrate conversions. Failures (PROM parse or CRC) keep the poller inactive and allow future retries or error reporting.

## Poller and timing

The barometer does not raise interrupts; instead, the driver runs a deterministic conversion sequence driven by a 1 kHz tick:

* `ms5611_poller_tick_1khz(ms5611_poller_t *p)` is called from `state_estimation_task_start` once per millisecond.
* The poller maintains a simple state machine:
  1. Issue a D1 (pressure) conversion command (`ms5611_submit_convert_d1`).
  2. Wait the required conversion time (`p->conv_us` converted to ticks).
  3. Read D1 via `ms5611_submit_read_d1` (uses the SPI job queue and DMA).
  4. Immediately issue a D2 (temperature) conversion (`ms5611_submit_convert_d2`).
  5. Wait, then read D2 (`ms5611_submit_read_d2`), compute compensated values, and enqueue a sample.
* The cycle repeats at the requested ODR (e.g., 50 Hz).

This polling avoids busy-waiting by spacing out conversions and using the SPI queue to perform each transaction asynchronously.

## SPI job flow

Each `*_submit_*` helper builds a `spi_job_t`:

* `cs_port` / `cs_pin` target `BARO1_CS`.
* `len` is determined by the command builder (`ms5611_build_convert_*` or `ms5611_build_adc_read`).
* `type` is `SPI_XFER_TX` for convert commands (only command bytes sent) and `SPI_XFER_TXRX` for ADC reads (command + dummy read).
* `done` is set for read jobs:
  * `ms5611_cb_read_d1` parses the ADC result from `rx[1]` (first byte is dummy), stores it in `p->dev.D1_raw`, and notes the timestamp.
  * `ms5611_cb_read_d2` parses the D2 result, calls `ms5611_compute` to derive temperature and pressure in centi-units, and creates an `ms5611_sample_t`.

Jobs are submitted to `jobq_spi_2` just like the BMI088 drivers, so the barometer shares the same DMA path and arbitration logic.

## Sample formatting and queueing

When both D1 and D2 have been collected, `ms5611_cb_read_d2` executes:

1. `ms5611_parse_adc_result` extracts a 24-bit raw value.
2. `ms5611_compute` runs the datasheet compensation formulas using stored calibration constants, producing:
   * `temp_centi` – temperature in 0.01 °C.
   * `pressure_centi` – pressure in 0.01 mbar (also equals 0.01 hPa).
3. A `ms5611_sample_t` is filled with timestamps (`t_us`), raw ADC readings, compensated values, and a monotonically increasing sequence number.
4. The sample is enqueued via `ms5611_sample_q_push(&ms5611_sample_ring, &sample)` for consumers to read later.

## Consumption by higher-level tasks

* The `state_estimation_task_start` loop dequeues up to 32 barometer samples per iteration and logs/uses them the same way as accelerometer/gyro samples.
* Downstream code can call `ms5611_fetch_latest` to obtain the most recent `ms5611_t` structure plus sequence number without draining the sample ring.
* The fused state published through `state_exchange_publish_state` incorporates barometric altitude as one of the navigation observables.

## Key properties

* **Deterministic cadence:** The conversion state machine ensures pressure and temperature are always paired, even though each requires a separate ADC cycle.
* **DMA-backed transfers:** Every SPI transaction, including the short convert commands, runs through the shared job queue, simplifying bus arbitration with other sensors.
* **Calibration-awareness:** PROM coefficients are read once at startup and cached, so subsequent computations are quick and performed entirely in firmware.
* **Thread-safe buffers:** The ring buffer decouples the high-rate poller from slower consumers, preventing timing jitter in the EKF loop.

With this driver, the MS5611 delivers high-resolution pressure data synchronized with the IMU streams, supporting accurate altitude estimation and flight-state decisions.

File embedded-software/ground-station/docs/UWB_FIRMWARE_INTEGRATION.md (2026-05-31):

# UWB Firmware Integration — Design Doc

**Status:** Pending UWB hardware purchase
**Audience:** Firmware author who picks up the rocket-side UWB work
**Written:** 2026-05-17 (after the GCS-side UWB loop landed and the firmware-side was reverted to keep the current rocket safe)
**Companion review notes:** `~/Downloads/gcs_review_2026-05-17.md` (not in repo; the author's session log)

---

## TL;DR

The Ground Control Station (GCS) side of the UWB anchor-layout / position-fix
pipeline is done. The flight-controller side is intentionally NOT implemented
yet — UWB hardware is not purchased, and shipping a half-wired feature would
risk current bench tests and flights. This doc is the handoff: everything the
firmware author needs to wire the loop when the MaUWB modules arrive.

The reference implementation existed briefly in commit `644b1f2 updated
version of GCS` on branch `embedded-software/feat/gcs-map-page` and was
reverted in a subsequent commit. Read that commit's diff for the original
patches — most of what's below restores them with the open questions resolved.

---

## What's already wired (GCS side, on this branch)

These are live. Don't touch them; the firmware author can rely on the wire
format being stable.

### Protocol — `embedded-software/libs/rocket-protocol/proto/tvr/`

```proto
// common.proto
message Vec2 {
  float x = 1;
  float y = 2;
}

// command.proto
message FlightCommand {
  oneof payload {
    StateCommand    state_cmd        = 1;
    SetPidGains     set_pid_gains    = 2;
    SetReference    set_reference    = 3;
    SetConfig       set_config       = 4;
    SetProbeLayout  set_probe_layout = 5;   // ← GCS uplink, FC consumer needed
  }
}

message SetProbeLayout {
  Vec2 anchor_0 = 1;
  Vec2 anchor_1 = 2;
  Vec2 anchor_2 = 3;
  Vec2 anchor_3 = 4;
}

// telemetry.proto — added to existing TelemetryState
message TelemetryState {
  ...
  Vec2 uwb_tag_0 = 10;   // ← FC populates when trilateration produces a fix
  Vec2 uwb_tag_1 = 11;
}
```

Generated headers under `libs/rocket-protocol/generated/tvr/` (regenerated;
do not hand-edit). Regenerate with:

```
cd embedded-software/libs/rocket-protocol
python3 -m venv /tmp/nanopb_venv && /tmp/nanopb_venv/bin/pip install protobuf
cat > /tmp/protoc-gen-nanopb-venv <<'EOF'
#!/bin/bash
exec /tmp/nanopb_venv/bin/python3 \
  $(pwd)/nanopb/generator/nanopb_generator.py --protoc-plugin
EOF
chmod +x /tmp/protoc-gen-nanopb-venv
protoc --plugin=protoc-gen-nanopb=/tmp/protoc-gen-nanopb-venv \
       -I proto/tvr -I nanopb/generator/proto \
       --nanopb_out=generated/tvr proto/tvr/*.proto
```
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

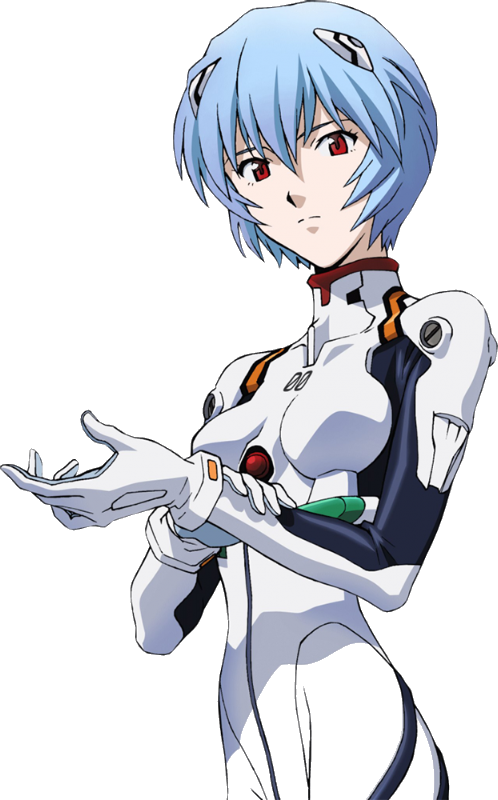
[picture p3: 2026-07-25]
embedded-software/ground-station/Resources/images/rei-cut.png

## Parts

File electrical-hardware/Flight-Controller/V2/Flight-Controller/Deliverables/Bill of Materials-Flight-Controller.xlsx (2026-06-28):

Manu Part # | Description | Designator | Footprint | Quantity | LCSC Part #
KMR231GLFS | Tactile Switch SPST 300gf 1.9mm Gull Wing 4.6mm x 2.8mm Surface Mount | B1 | KMR231GLFS | 1 | C99271
QMB-09B-05 | -40℃~+85℃ 2.7kHz 3V~7V 5.7mm 5V 60mA 80dB 9mm Electromagnetic Passive (Externally Driven) 插件,D=9mm Buzzers ROHS | BZ1 | QMB-09B-05 | 1 | C161819
CL21A226MAQNNNE | 22uF ±20% 25V Ceramic Capacitor X5R 0805 | C1, C42, C64, C65 | CAPC2012X145N | 4 | C45783
CC0603KRX7R9BB104 | 50V 100nF X7R ±10% 0603 Multilayer Ceramic Capacitors MLCC - SMD/SMT ROHS | C2, C3, C5, C6, C7, C8, C9, C10, C11, C12, C13, C14, C15, C16, C17, C21, C22, C24, C26, C29, C30, C31, C32, C34, C37, C40, C44, C49, C50, C52, C53, C54, C56, C57, C58, C59, C60, C61, C62 | CAPC1608X90N | 39 | C14663
CL10A105KB8NNNC | 50V 1uF X7R ±10% 0603 Multilayer Ceramic Capacitors MLCC - SMD/SMT ROHS | C4, C18, C25, C36, C51 | CAPC1608X90N | 5 | C15849
CL10A225KO8NNNC | 2.2 µF ±10% 25V Ceramic Capacitor X5R 0603 (1608 Metric) | C19, C20, C35 | CAPC1608X90N | 3 | C23630
CL10A475KO8NNNC | 16V 4.7uF X5R ±10% 0603 Multilayer Ceramic Capacitors MLCC - SMD/SMT ROHS | C23 | CAPC1608X90N | 1 | C19666
CL10C120JB8NNNC | 12pF ±1% 50V Ceramic Capacitor NP0 0603 | C27, C28 | CAPC1608X90N | 2 | C38523
0603B103K500NT | 10nF ±10% 50V Ceramic Capacitor X7R 0603 | C33, C39, C45 | CAPC1608X90N | 3 | C57112
CL10A106KP8NNNC | 10uF ±10% 10V Ceramic Capacitor X5R 0603 | C38, C41, C43, C55 | CAPC1608X90N | 4 | C19702
CL10C470JB8NNNC | 47 pF ±5% 50V Ceramic Capacitor C0G, NP0 0603 (1608 Metric) | C46, C66 | CAPC1608X90N | 2 | C1671
CC0603KRX7R9BB103 | 10nF ±10% 50V Ceramic Capacitor X7R 0603 | C47, C48 | CAPC1608X90N | 2 | C100042
GRM21BR61H106KE43L | 10uF 50V X5R ±10% 0805 Multilayer Ceramic Capacitors MLCC - SMD/SMT ROHS | C63 | CAPC2012X145N | 1 | C440198
1N5819HW-7-F | 25A 1 Independent 40V 450mV@1A 1A SOD-123 Single Diodes RoHS | D1 | SOD3716X125N | 1 | C82544
BAT54XV2T1G | Diode 30V 200mA Surface Mount SOD-523 | D2, D3 | SOD523 | 2 | C81572
BLM18AG601SN1D | 380mΩ ±25% 600Ω@100MHz 0603 Ferrite Beads ROHS | FB1 | BLM18SP221SN1B | 1 | C19330
BLM18SG330SN1D | 33Ω@100MHz 1 Line Ferrite Bead 0603 6A 8mΩ | FB2 | BLM18SP221SN1B | 1 | C576399
STM32H745ZIT6 | Dual 32-bit Arm Cortex-M7 and -M4 MCUs, up to 2MB Flash, 1MB RAM, 46 com. and analog interfaces, SMPS | IC1 | QFP50P2200X2200X160-144N | 1 | C730193
BMI088 | Inertial Measurement Unit IMU 6-Axis LGA | IC2 | BMI088 | 1 | C194919
MS561101BA03-50 | Barometric Pressure Sensor, with Stainless Steel Cap, 1.8 to 3.6 V, -45 to 85 degC, 8-Pin QFN, RoHS, Tape and Reel | IC3 | MSI-MS561101BA03-50-8_V | 1 | C15639
ICM-40609-D | LGA24-3x3 IMUs (Inertial Measurement Units) RoHS | IC4 | LGA-24_L3.0-W3.0-P0.40-TL | 1 | C5360621
MMC5983MA | ±8 Gauss, High Performance 3-axis Magnetic Sensor | IC5 | LGA-16_L3.0-W3.0-P0.50-BL_SQ | 1 | C404329
AMS1117-3.3 | 70dB@(120Hz) 1.35A Fixed 3.3V Positive 10V SOT-223 Voltage Regulators - Linear, Low Drop Out (LDO) Regulators ROHS | IC6 | SOT230P700X180-4N | 1 | C6186
ESDA6V1BC6 | Clamp Ipp Tvs Diode Surface Mount SOT-23-6 | IC7, IC8, IC9 | SOT95P280X145-6N | 3 | C495220
DP83848IVVX/NOPB | Single Port 10/100 Mb/s Ethernet Physical Layer Transceiver | IC10 | QFP50P900X900X160-48N | 1 | C12082
TXS0104EPWR | 4-Bit Bidirectional Voltage-Level Translator For Open-Drain and Push-Pull Applications | IC11 | TXB0104PWR | 1 | C44955
SN74LVC2G241DCTR | SN74LVC2G241 Dual Buffer and Driver with Three-State Outputs | IC12 | SOP65P400X130-8N | 1 | C2676069
AP63300WU-7 | 3.8V to 32V Input, 3A Low IQ Synchronous Buck Converter with Enhanced EMI Reduction | IC13 | SOT95P280X90-6N | 1 | C2158012
S4B-PH-K-S(LF)(SN) | Connector Header 4 position 2mm Pitch 2A Right Angle -25℃~+85℃ | J2, J3, J4, J5 | S4B-PH-K-S-_LF_SN | 4 | C157926
S2B-PH-K-S(LF)(SN) | Connector Header 2 position 2mm Pitch 2A Right Angle -25℃~+85℃ | J6, J8, J9 | S2B-PH-K-S_LF_SN | 3 | C173752
S3B-PH-K-S(LF)(SN) | Connector Header 3 position 2mm Pitch 2A Right Angle -25℃~+85℃ | J7 | S3B-PH-K-S-_LF_SN | 1 | C157929
TF-01A | Micro SD card (TF card) Connector and Ejector Push-Push Surface Mount | J10 | TF-SMD_TF-01A | 1 | C41426929
GT-USB-7010ASV | USB 2.0 3A 1 Surface Mount, Right Angle 16P Female -40℃~+85℃ Type-C SMD USB Connectors ROHS | J11 | USB-C-SMD_G-SWITCH_GT-USB-7010ASV | 1 | C2988369
BWSMA-KWE-Z001 | Connector Receptacle SMA Female Pin 50Ω Through Hole Right Angle | J12 | SMA-TH_BWSMA-KWE-Z001 | 1 | C496551
HB-PH9-12727PB2GOB | Pin Header 2 1mm 4mm 14P -40℃~+105℃ 1.27mm 1A 250V 2x7P 1.27mm SMD,P=1.27mm Headers, Male Pins RoHS | J13 | HB-PH9-12727PB2GOB | 1 | C6332251
XT60PW-F | Horizontal plug Yellow - Power connector / plug connector | J14 | XT60PW-F_C428722 | 1 | C428722
DB125-2.54-4P-GN-S | 4 Position Wire to Board Terminal Block Through Hole 2.54mm | J15 | DB125-2_54-4P-GN | 1 | C918122
LQG18HN27NJ00D | 27 nH Unshielded Multilayer Inductor 500 mA 550mOhm Max 0603 (1608 Metric) | L1 | INDC1608X90N | 1 | C162550
FXL0630-6R8-M | 48mΩ 5A 6.8uH 6A Molded Inductor ±20% SMD,7x6.6mm Power Inductors ROHS | L2 | FXL0630-6R8-M | 1 | C167221
KT-0603R | -40℃~+85℃ 1.8V~2.4V 120° 20mA 300mcd 40mW 615nm~630nm 645nm Discrete Diode Red Water Clear 0603 LED Indication - Discrete ROHS | LED1, LED3 | LEDC1608X36N | 2 | C2286
SML-E12P8WT86 | Green LED Indication - Discrete 2.2V 0603 | LED2, LED4 | LEDC1608X36N | 2 | C126319
SML-D12Y1WT86 | Yellow LED Indication - Discrete 2.2V 0603 | LED5 | LEDC1608X36N | 1 | C253534
2N7002 | N-Channel 60V 300mA 830mW Surface Mount SOT-23 | Q1, Q2, Q3, Q5, Q6, Q7, Q8 | SOT95P230X110-3N | 7 | C8545
BSS8402DW-7-F | N-Channel+P-Channel Array 60V 130mA 200mW Surface Mount SOT-363 | Q4 | SOT65P210X110-6N | 1 | C156386
0603WAF4700T5E | -55℃~+155℃ 100mW 470Ω 75V Thick Film Resistor ±1% ±100ppm/℃ 0603 Chip Resistor - Surface Mount ROHS | R1, R29, R30, R31, R64, R66, R68 | RESC1608X90N | 7 | C23179
0603WAF0000T5E | 0Ω 100mW 75V Thick Film Resistor ±1% 0603 Chip Resistor - Surface Mount RoHS | R2, R27, R28 | RESC1608X90N | 3 | C21189
0603WAF1002T5E | 100mW Thick Film Resistor 75V ±100ppm/℃ ±1% 10kΩ 0603 Chip Resistor - Surface Mount ROHS | R3, R9, R10, R11, R12, R13, R14, R15, R16, R17, R18, R19, R20, R21, R22, R23, R48, R53, R54, R55, R56, R59, R61, R63, R65, R67, R69 | RESC1608X90N | 27 | C25804
0603WAF1001T5E | 100mW 1kΩ 75V Thick Film Resistor ±100ppm/℃ ±1% 0603 Chip Resistor - Surface Mount RoHS | R4, R6, R24, R60 | RESC1608X90N | 4 | C21190
0603WAF330JT5E | 100mW 33Ω 75V Thick Film Resistor ±100ppm/℃ ±1% 0603 Chip Resistor - Surface Mount RoHS | R5, R7, R8, R41, R44, R45, R49 | RESC1608X90N | 7 | C23140
RC0603FR-075K1L | 100mW 5.1kΩ 75V Thick Film Resistor ±100ppm/℃ ±1% 0603 Chip Resistor - Surface Mount RoHS | R25, R26 | RESC1608X55N | 2 | C105580
0603WAF2201T5E | 2.2kΩ ±1% 100mW 0603 Thick Film Resistor | R32, R36, R37 | RESC1608X90N | 3 | C4190
0603WAF2201T5E | 2.2kΩ ±1% 100mW 0603 Thick Film Resistor | R33, R34, R35, R38, R39, R40, R47 | RESC1608X90N | 7 | C4190
0603WAF499JT5E | -55℃~+155℃ 100mW 49.9Ω 75V Thick Film Resistor ±1% ±100ppm/℃ 0603 Chip Resistor - Surface Mount ROHS | R42, R43, R50, R51 | RESC1608X90N | 4 | C23185
0603WAF1501T5E | 100mW 1.5kΩ 75V Thick Film Resistor ±100ppm/℃ ±1% 0603 Chip Resistor - Surface Mount RoHS | R46 | RESC1608X90N | 1 | C22843
RC0603FR-074K87L | 4.87kΩ 100mW 75V Thick Film Resistor ±100ppm/℃ ±1% 0603 Chip Resistor - Surface Mount RoHS | R52 | RESC1608X55N | 1 | C137709
0603WAF1583T5E | -55℃~+155℃ 100mW 158kΩ 75V Thick Film Resistor ±1% ±100ppm/℃ 0603 Chip Resistor - Surface Mount ROHS | R57 | RESC1608X90N | 1 | C22883
0603WAF3002T5E | -55℃~+155℃ 100mW 30kΩ 75V Thick Film Resistor ±1% ±100ppm/℃ 0603 Chip Resistor - Surface Mount ROHS | R58 | RESC1608X90N | 1 | C22984
0603WAF1200T5E | -55℃~+155℃ 100mW 120Ω 75V Thick Film Resistor ±1% ±100ppm/℃ 0603 Chip Resistor - Surface Mount ROHS | R62 | RESC1608X90N | 1 | C22787
MAX-M10S-00B | Standard precision GNSS module | U1 | XCVR_MAX-M10S-00B | 1 | C4153167
XC32M4-24.000-F12NJDTL | Crystal 24MHz ±10ppm 12pF 50Ω SMD3225-4P | Y1 | CRYSTAL-SMD_4P-L3.2-W2.5-BL | 1 | C5122304
SX3M50.000M20F30TNN | Oscillator 50MHz ±20ppm CMOS 1.62V~3.63V SMD3225-4P | Y2 | SX3M50_000M20F30TNN | 1 | C2901592

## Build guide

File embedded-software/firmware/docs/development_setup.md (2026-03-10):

# Development Setup Guide

This document describes instructions to setup an environment for developing and
building the Ulysses firmware.

## Table of contents

<!-- autogenerated TOC begin -->
<!-- markdownlint-capture -->
<!-- markdownlint-disable -->

- [Development Setup Guide](#development-setup-guide)
    - [Table of contents](#table-of-contents)
    - [Installing the toolchain](#installing-the-toolchain)
        - [Installing STM32CubeIDE](#installing-stm32cubeide)
        - [Installing ARM GNU Toolchain](#installing-arm-gnu-toolchain)
            - [Installing ARM GNU Toolchain using an archive](#installing-arm-gnu-toolchain-using-an-archive)
            - [Installing ARM GNU Toolchain using an installer](#installing-arm-gnu-toolchain-using-an-installer)
        - [Installing Ninja](#installing-ninja)
        - [Installing CMake](#installing-cmake)
    - [Optional tools](#optional-tools)
        - [Installing STM32CubeMX](#installing-stm32cubemx)
    - [Setting up VS Code](#setting-up-vs-code)
        - [Installing VS Code](#installing-vs-code)
        - [Installing recommended extensions](#installing-recommended-extensions)
    - [Adding debugging support to VS Code](#adding-debugging-support-to-vs-code)
        - [Getting necessary OpenOCD paths](#getting-necessary-openocd-paths)
            - [Windows](#windows)
            - [macOS](#macos)
            - [Linux](#linux)
        - [Configuring the Cortex-Debug extension for OpenOCD](#configuring-the-cortex-debug-extension-for-openocd)
    - [See also](#see-also)

<!-- markdownlint-restore -->
<!-- autogenerated TOC end -->

## Installing the toolchain

### Installing STM32CubeIDE

> [!important]
> You will need a myST account to download and install this tool.

[STM32CubeIDE][stm32cubeide] is the IDE provided by ST for developing software
on STM32 MCUs and MPUs.

It can be installed by downloading and running the appropriate installer for
your operating system in the `Get Software` section on its web page.

We will not use STM32CubeIDE for development (i.e. editing source code and
debugging). However, its installation provides a pre-compiled distribution
of [ST's customized version of OpenOCD][stm_openocd], that we will use as
the GDB server. This is as the upstream OpenOCD currently does not support the
`STM32H563` MCU we are using.

[stm32cubeide]: https://www.st.com/en/development-tools/stm32cubeide.html
[stm_openocd]: https://github.com/STMicroelectronics/OpenOCD

### Installing ARM GNU Toolchain

The [Arm GNU Toolchain][arm_gnu_toolchain] is the GNU cross-compiler toolchain
for Arm targets.

To download the toolchain, scroll down and expand the accordion menu for the
version of the toolchain you want (the latest version is expanded by default).
In the menu, find the toolchain with a host (shown in bolded text on the page)
that matches your current machine (e.g. Windows, Linux, macOS). In the section
for your host, download the toolchain for a
`AArch32 bare-metal target (arm-none-eabi)`.

Depending on your host, the toolchain may be installed through different
methods as described below.

You can verify if you have installed the toolchain correctly by running the
following commands depending on your host.

```shell
# Windows
arm-none-eabi-gcc.exe --version

# macOS
arm-none-eabi-gcc --version

# Linux
arm-none-eabi-gcc --version
```

[arm_gnu_toolchain]: https://developer.arm.com/downloads/-/arm-gnu-toolchain-downloads

#### Installing ARM GNU Toolchain using an archive

The most basic installation method is to download an archive of the toolchain
and extract it to a known location and adding the `bin/` folder of the toolchain
to the system PATH. The `bin/` folder added should contain binaries named as
`arm-none-eabi-*`.

#### Installing ARM GNU Toolchain using an installer

> [!note]
> There is no installer provided for Linux hosts.

For Windows and macOS hosts, you can download an installer which simply extracts
the toolchain to some location. For Windows, the installer shows the location
to which it will place the toolchain. For macOS, it may not show the location
and so you may need to look around common application install locations to find
it. After finding a path to the toolchain, you can follow the same steps as in
[installing using the archive](#installing-arm-gnu-toolchain-using-the-archive)
to add it to the system PATH.

### Installing Ninja

[Ninja][ninja_build] is the build system we use for the firmware. You will not
interact with it directly, but rather through CMake.

It can be installed by following the steps on the site.

You can verify your installation by running the command

```shell
ninja --version
```

[ninja_build]: https://ninja-build.org

### Installing CMake

[CMake][cmake] is the meta-build system that we use for the firmware.

Follow the instructions on its site to download and install it for your host
machine. Ensure that you are using a version greater or equal to `3.22`.

You can verify your installation by running the command

```shell
cmake --version
```

[cmake]: https://cmake.org

## Optional tools

These are tools that are not used regularly for development but may have
a purpose for certain situations.

### Installing STM32CubeMX

> [!important]
> You will need a myST account to download and install this tool.

[STM32CubeMX][stm32cubemx] is a tool provided by ST for graphically configuring
STM32 MCUs and MPUs, as well as provide generation of initialization code.

It can be installed by downloading and running the appropriate installer for
your operating system in the `Get Software` section on its web page.

We use STM32CubeMX for configuring pins on our MCU as well as bootstrapping the
initial project. Configuration files for STM32CubeMX have the extension `.ioc`.

[stm32cubemx]: https://www.st.com/en/development-tools/stm32cubemx.html

## Setting up VS Code

We use [Visual Studio Code (VS Code)][vscode] as our primary development editor.

[vscode]: https://code.visualstudio.com

### Installing VS Code

Follow the steps provided by the official guide on
[Setting up Visual Studio Code][setting_up_vscode].

[setting_up_vscode]: https://code.visualstudio.com/docs/setup/setup-overview

### Installing recommended extensions

> [!important]
> Unless you have your own working extension setup, you should definitely
> install these recommended extensions.

To view the recommended extensions, open the VS Code Command Palette
(`Ctrl+Shift+P` or `Cmd+Shift+P`) and run the
`Extensions: Show Recommended Extensions` command. This will open up the
`WORKSPACE RECOMMENDATIONS` section of the `EXTENSIONS` sidebar. To download all
the recommended extensions, click the `Install Workspace Recommended Extensions`
button (displayed as a cloud icon).

Alternatively, you can install the recommended extensions manually using the
extension identifiers listed in `.vscode/extensions.json`.

## Adding debugging support to VS Code

This section will describe how to setup remote debugging support in VS Code for
the firmware.

As we are using ST's customized OpenOCD, we will need to quite a bit of
configuration to have Cortex-Debug use it as the GDB server.

### Getting necessary OpenOCD paths

To properly configure Cortex-Debug, we will need to know two paths

- `OPENOCD_BINARY_PATH`: Path to the OpenOCD binary
- `STM32_OPENOCD_SCRIPTS_PATH`: Path to the OpenOCD scripts folder

#### Windows

The `OPENOCD_BINARY_PATH` depends on your version of STM32CubeIDE, but should
generally be similar to

```text
D:/ST/STM32CubeIDE_1.19.0/STM32CubeIDE/plugins/com.st.stm32cube.ide.mcu.externaltools.openocd.win32_2.4.200.202505051030/tools/bin/openocd.exe
```

Similarly, `STM32_OPENOCD_SCRIPTS_PATH` will look like

```text
D:/ST/STM32CubeIDE_1.19.0/STM32CubeIDE/plugins/com.st.stm32cube.ide.mcu.debug.openocd_2.3.100.202501240831/resources/openocd/st_scripts
```

> [!tip]
> Convert these paths to be in a UNIX path format (forward slashes) to make
> handling them in strings easier.

#### macOS

`OPENOCD_BINARY_PATH` will resemble

```text
/Applications/STM32CubeIDE.app/Contents/Eclipse/plugins/com.st.stm32cube.ide.mcu.externaltools.openocd.macos64_2.4.200.202505051030/tools/bin/openocd
```

`STM32_OPENOCD_SCRIPTS_PATH` will resemble

```text
/Applications/STM32CubeIDE.app/Contents/Eclipse/plugins/com.st.stm32cube.ide.mcu.debug.openocd_2.3.100.202501240831/resources/openocd/st_scripts
```

#### Linux

### Configuring environment variables for OpenOCD

The debug launch configurations reference two environment variables. You must
set both of these in your shell profile (e.g. `~/.bashrc`, `~/.zshrc`, or
`~/.config/fish/config.fish`).

See the [README](../../../README.md#environment-variables) for platform-specific path
examples.

| Variable | Purpose |
|---|---|
| `STM32_OPENOCD_PATH` | Path to the OpenOCD **binary** bundled with STM32CubeIDE |
| `STM32_OPENOCD_SCRIPTS_PATH` | Path to the OpenOCD **st_scripts** directory |

For example, on Linux you would add the following to your `~/.bashrc`:

```shell
export STM32_OPENOCD_PATH="/opt/st/stm32cubeide_<version>/plugins/com.st.stm32cube.ide.mcu.externaltools.openocd.linux64_<version>/tools/bin/openocd"
export STM32_OPENOCD_SCRIPTS_PATH="/opt/st/stm32cubeide_<version>/plugins/com.st.stm32cube.ide.mcu.debug.openocd_<version>/resources/openocd/st_scripts"
```

> [!important]
> You must restart VS Code (and potentially your shell) after adding the
> environment variables to get VS Code to recognize them.

## See also

[Cortex-Debug extension wiki](https://github.com/Marus/cortex-debug/wiki)

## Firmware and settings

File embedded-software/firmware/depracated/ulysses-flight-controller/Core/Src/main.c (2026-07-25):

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
/* Includes ------------------------------------------------------------------*/
#include "main.h"
#include "cmsis_os2.h"
#include "dcache.h"
#include "gpdma.h"
#include "icache.h"
#include "sdmmc.h"
#include "spi.h"
#include "tim.h"
#include "usart.h"
#include "usb.h"
#include "gpio.h"

/* USER CODE BEGIN Includes */
#include "debug/log.h"
#include "sensors_init.h"
#include "timestamp.h"
#include "spi1_bus.h"
#include "gnss_radio_master.h"
#include "motor_drivers/servo_driver.h"
#include "motor_drivers/esc_driver.h"
/* USER CODE END Includes */

/* USER CODE BEGIN PM */

static bool sd_card_is_inserted(void)
{
  GPIO_PinState state = HAL_GPIO_ReadPin(SD_CARD_DETECT_GPIO_Port, SD_CARD_DETECT_Pin);
  /* Assuming the detect pin is low when a card is present. Adjust if hardware differs. */
  return state == GPIO_PIN_RESET;
}

/* USER CODE END PM */


/* USER CODE BEGIN PV */
bool g_sd_card_initialized = false;

/* USER CODE END PV */

void SystemClock_Config(void);
void MX_FREERTOS_Init(void);
/* USER CODE BEGIN PFP */
static HAL_StatusTypeDef sd_enable_internal_dma(SD_HandleTypeDef *hsd);

/* USER CODE END PFP */

/**
  * @brief  The application entry point.
  * @retval int
  */
int main(void)
{

  /* MCU Configuration--------------------------------------------------------*/

  /* Reset of all peripherals, Initializes the Flash interface and the Systick. */
  HAL_Init();

  /* Configure the system clock */
  SystemClock_Config();

  /* USER CODE BEGIN SysInit */
  /* Initialize high-resolution timestamp (enables DWT cycle counter) */
  timestamp_init();
  /* USER CODE END SysInit */

  /* Initialize all configured peripherals */
  MX_GPIO_Init();
  MX_GPDMA2_Init();
  MX_GPDMA1_Init();
  MX_SDMMC1_SD_Init();
  MX_SPI1_Init();
  MX_SPI2_Init();
  MX_SPI4_Init();
  MX_UART4_Init();
  MX_USART2_UART_Init();
  MX_USART1_UART_Init();
  MX_USB_PCD_Init();
  MX_TIM3_Init();
  MX_TIM1_Init();
  MX_TIM2_Init();
  MX_TIM4_Init();
  MX_DCACHE1_Init();
  MX_ICACHE_Init();
  /* USER CODE BEGIN 2 */

  /* --- TIM4 interrupt channels ------------------------------------ */
  HAL_TIM_OC_Start_IT(&htim4, TIM_CHANNEL_2);   /* 800 Hz -> controls notify */
  HAL_TIM_OC_Start_IT(&htim4, TIM_CHANNEL_4);   /* 800 Hz -> ESC/servo/baro */

  /* --- Servo pair: TIM1 CH2 (servo1), TIM3 CH3 (servo2) - 200Hz -- */
  {
    pwm_output_t pwm1 = {
      .htim        = &htim1,
      .channel     = TIM_CHANNEL_2,
      .timer_hz    = 1000000U,
      .period_ticks = 5000U,
    };
    pwm_output_t pwm2 = {
      .htim        = &htim3,
      .channel     = TIM_CHANNEL_3,
      .timer_hz    = 1000000U,
      .period_ticks = 5000U,
    };
    servo_pair_init(&pwm1, &pwm2);
    servo_pair_enable(true);
  }

  /* --- ESC pair: TIM2 CH2 (esc1), TIM2 CH4 (esc2) - 400Hz ------- */
  {
    pwm_output_t pwm1 = {
      .htim        = &htim2,
      .channel     = TIM_CHANNEL_2,
      .timer_hz    = 1000000U,
      .period_ticks = 2500U,
    };
    pwm_output_t pwm2 = {
      .htim        = &htim2,
      .channel     = TIM_CHANNEL_4,
      .timer_hz    = 1000000U,
      .period_ticks = 2500U,
    };
    esc_pair_init(&pwm1, &pwm2);
  }

#ifdef ULYSSES_ENABLE_DEBUG_LOGGING
  debug_log_init(&huart1);
#endif // ULYSSES_ENABLE_DEBUG_LOGGING

  if (g_sd_card_initialized) {
    if (sd_enable_internal_dma(&hsd1) != HAL_OK) {
      Error_Handler();
    }
  }

  /*
   * Initialize all SPI sensors before starting the scheduler.
   * This avoids long blocking operations inside tasks with interrupts disabled.
   * The sensor init takes ~700ms due to device reset delays.
   */
  sensors_init_status_t sensor_status = sensors_init();

  /* Optional: Check sensor status and handle failures */
  if (!sensors_init_critical_ok(&sensor_status)) {
    /* IMU initialization failed - system may not be flight-ready */
#ifdef ULYSSES_ENABLE_DEBUG_LOGGING
    /* Log the error codes for debugging */
    (void)sensor_status;  /* Avoid unused warning in release builds */
#endif
    /* Continue anyway - tasks will check ready flags */
  }

  /* USER CODE END 2 */

  /* Init scheduler */
  osKernelInitialize();
  /* Call init function for freertos objects (in app_freertos.c) */
  MX_FREERTOS_Init();

  /* Start scheduler */
  osKernelStart();

  /* We should never get here as control is now taken by the scheduler */

  /* Infinite loop */
  /* USER CODE BEGIN WHILE */
  while (1)
  {
    /* USER CODE END WHILE */

    /* USER CODE BEGIN 3 */
  }
  /* USER CODE END 3 */
}

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
/* USER CODE BEGIN 4 */
static HAL_StatusTypeDef sd_enable_internal_dma(SD_HandleTypeDef *hsd)
{
#if defined(SDMMC_ENABLE_IDMA_SINGLE_BUFF)
  hsd->Instance->IDMACTRL = SDMMC_ENABLE_IDMA_SINGLE_BUFF;
  return HAL_OK;
#else
  (void)hsd;
  return HAL_ERROR;
#endif
}

/* USER CODE END 4 */

/**
  * @brief  Period elapsed callback in non blocking mode
  * @note   This function is called  when TIM6 interrupt took place, inside
  * HAL_TIM_IRQHandler(). It makes a direct call to HAL_IncTick() to increment
  * a global variable "uwTick" used as application time base.
  * @param  htim : TIM handle
  * @retval None
  */
void HAL_TIM_PeriodElapsedCallback(TIM_HandleTypeDef *htim)
{
  if (htim->Instance == TIM6)
  {
    HAL_IncTick();
  }
}

/**
  * @brief  This function is executed in case of error occurrence.
  * @retval None
  */
void Error_Handler(void)
{
  /* USER CODE BEGIN Error_Handler_Debug */
  /* User can add his own implementation to report the HAL error return state */
  __disable_irq();
  while (1)
  {
  }
  /* USER CODE END Error_Handler_Debug */
}
#ifdef USE_FULL_ASSERT
/**
  * @brief  Reports the name of the source file and the source line number
  *         where the assert_param error has occurred.
  * @param  file: pointer to the source file name
  * @param  line: assert_param error line source number
  * @retval None
  */
void assert_failed(uint8_t *file, uint32_t line)
{
  /* USER CODE BEGIN 6 */
  /* User can add his own implementation to report the file name and line number,
     ex: printf("Wrong parameters value: file %s on line %d\r\n", file, line) */
  /* USER CODE END 6 */
}
#endif /* USE_FULL_ASSERT */

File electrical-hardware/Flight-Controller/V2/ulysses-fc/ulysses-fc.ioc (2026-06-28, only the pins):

Mcu.UserName=STM32H745ZITx
PA0.Signal=S_TIM2_CH1_ETR
PA1.Signal=ETH_REF_CLK
PA10.Signal=LPUART1_RX
PA11.Signal=SPI2_NSS
PA12.Signal=SPI2_SCK
PA2.Signal=ETH_MDIO
PA3.GPIO_Label=PHY_INT
PA3.Signal=GPXTI3
PA4.Signal=SPI3_NSS
PA5.Signal=SPI6_SCK
PA6.Signal=S_TIM3_CH1
PA7.Signal=ETH_CRS_DV
PA8.Signal=S_TIM1_CH1
PA9.Signal=LPUART1_TX
PB0.Signal=ADCx_INP9
PB1.Signal=S_TIM3_CH4
PB10.Signal=S_TIM2_CH3
PB11.Signal=ETH_TX_EN
PB12.Signal=ETH_TXD0
PB13.Signal=ETH_TXD1
PB14.Signal=USART1_TX
PB15.Signal=USART1_RX
PB2.Signal=SPI3_MOSI
PB5.Signal=UART5_RX
PB6.Signal=UART5_TX
PB7.GPIO_Label=STAT_LEDR
PB7.Signal=GPIO_Output
PB8.Signal=FDCAN1_RX
PB9.Signal=FDCAN1_TX
PC0.GPIO_Label=GNSS_RST
PC0.Signal=GPIO_Output
PC1.Signal=ETH_MDC
PC10.Signal=SDMMC1_D2
PC11.Signal=SDMMC1_D3
PC12.Signal=SDMMC1_CK
PC13.GPIO_Label=BMI_ACC_INT1
PC13.Signal=GPXTI13
PC2_C.Signal=SPI2_MISO
PC3_C.Signal=SPI2_MOSI
PC4.Signal=ETH_RXD0
PC5.Signal=ETH_RXD1
PC6.Signal=USART6_TX
PC7.Signal=USART6_RX
PC8.Signal=SDMMC1_D0
PC9.Signal=SDMMC1_D1
PD0.Signal=UART4_RX
PD1.Signal=UART4_TX
PD10.GPIO_Label=RGB_B
PD10.Signal=GPIO_Output
PD11.GPIO_Label=EXTRA_PD11
PD11.Signal=GPIO_Output
PD12.Signal=S_TIM4_CH1
PD13.Signal=S_TIM4_CH2
PD14.GPIO_Label=RGB_G
PD14.Signal=GPIO_Output
PD15.Signal=UART8_DE
PD2.Signal=SDMMC1_CMD
PD3.GPIO_Label=LVL_SHIFT_OE
PD3.Signal=GPIO_Output
PD4.GPIO_Label=SD_CARD_DETECT
PD4.Signal=GPXTI4
PD5.Signal=USART2_TX
PD6.Signal=USART2_RX
PD7.Signal=SPI1_MOSI
PD8.Signal=USART3_TX
PD9.Signal=USART3_RX
PE0.Signal=UART8_RX
PE1.Signal=UART8_TX
PE10.GPIO_Label=EXTRA_PE10
PE10.Signal=GPIO_Output
PE11.Signal=S_TIM1_CH2
PE12.GPIO_Label=ICM_INT1
PE12.Signal=GPXTI12
PE13.GPIO_Label=EXTRA_PE13
PE13.Signal=GPIO_Output
PE14.GPIO_Label=PHY_RST
PE14.Signal=GPIO_Output
PE15.GPIO_Label=ICM_INT2
PE15.Signal=GPXTI15
PE2.Signal=SPI4_SCK
PE3.GPIO_Label=BMI_ACC_CS
PE3.Signal=GPIO_Output
PE4.GPIO_Label=BMI_GYRO_CS
PE4.Signal=GPIO_Output
PE5.Signal=SPI4_MISO
PE6.Signal=SPI4_MOSI
PE7.Signal=UART7_RX
PE8.Signal=UART7_TX
PE9.GPIO_Label=EXTRA_PE9
PE9.Signal=GPIO_Output
PF10.GPIO_Label=BMI_GYRO_INT1
PF10.Signal=GPXTI10
PF11.Signal=SPI5_MOSI
PF14.Signal=I2C4_SCL
PF15.Signal=I2C4_SDA
PF6.Signal=SPI5_NSS
PF7.Signal=SPI5_SCK
PF8.Signal=SPI5_MISO
PF9.GPIO_Label=BMI_GYRO_INT2
PF9.Signal=GPXTI9
PG10.Signal=SPI1_NSS
PG11.Signal=SPI1_SCK
PG12.Signal=SPI6_MISO
PG13.GPIO_Label=EXTRA_PG13
PG13.Signal=GPIO_Output
PG14.Signal=SPI6_MOSI
PG6.GPIO_Label=MMC_INT
PG6.Signal=GPXTI6
PG7.GPIO_Label=RGB_R
PG7.Signal=GPIO_Output
PG8.Signal=SPI6_NSS
PG9.Signal=SPI1_MISO

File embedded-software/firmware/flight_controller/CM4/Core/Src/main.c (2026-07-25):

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
/* Includes ------------------------------------------------------------------*/
#include "main.h"
#include "FreeRTOS.h"
#include "cmsis_os2.h"
#include "bdma.h"
#include "crc.h"
#include "dma.h"
#include "i2c.h"
#include "usart.h"
#include "rng.h"
#include "sdmmc.h"
#include "spi.h"
#include "tim.h"
#include "wwdg.h"
#include "gpio.h"

/* USER CODE BEGIN Includes */
#include "io_sys/io_init.h"
#include "io_sys/io_timestamp.h"
#include "app/app_init.h"
#include "dev_baro_ms5611.h"   /* TIM7 update → baro conversion pacer */
/* USER CODE END Includes */

/* USER CODE BEGIN PD */

/* DUAL_CORE_BOOT_SYNC_SEQUENCE: Define for dual core boot synchronization    */
/*                             demonstration code based on hardware semaphore */
/* This define is present in both CM7/CM4 projects                            */
/* To comment when developping/debugging on a single core                     */
/* UBC Rocket MVP bring-up: boot-sync DISABLED so the M4 runs standalone and
 * does NOT wait on the M7's HSEM (the fragile handoff that was stalling it).
 * The M7 is parked in __WFI(). Re-enable on both cores for dual-core ops. */
/* #define DUAL_CORE_BOOT_SYNC_SEQUENCE */

#if defined(DUAL_CORE_BOOT_SYNC_SEQUENCE)
#ifndef HSEM_ID_0
#define HSEM_ID_0 (0U) /* HW semaphore 0*/
#endif
#endif /* DUAL_CORE_BOOT_SYNC_SEQUENCE */

/* USER CODE END PD */


void MX_FREERTOS_Init(void);
/**
  * @brief  The application entry point.
  * @retval int
  */
int main(void)
{

/* USER CODE BEGIN Boot_Mode_Sequence_1 */
#if defined(DUAL_CORE_BOOT_SYNC_SEQUENCE)
  /*HW semaphore Clock enable*/
  __HAL_RCC_HSEM_CLK_ENABLE();
  /* Activate HSEM notification for Cortex-M4*/
  HAL_HSEM_ActivateNotification(__HAL_HSEM_SEMID_TO_MASK(HSEM_ID_0));
  /*
  Domain D2 goes to STOP mode (Cortex-M4 in deep-sleep) waiting for Cortex-M7 to
  perform system initialization (system clock config, external memory configuration.. )
  */
  HAL_PWREx_ClearPendingEvent();
  HAL_PWREx_EnterSTOPMode(PWR_MAINREGULATOR_ON, PWR_STOPENTRY_WFE, PWR_D2_DOMAIN);
  /* Clear HSEM flag */
  __HAL_HSEM_CLEAR_FLAG(__HAL_HSEM_SEMID_TO_MASK(HSEM_ID_0));

#endif /* DUAL_CORE_BOOT_SYNC_SEQUENCE */
/* USER CODE END Boot_Mode_Sequence_1 */
  /* MCU Configuration--------------------------------------------------------*/

  /* Reset of all peripherals, Initializes the Flash interface and the Systick. */
  HAL_Init();

  /* USER CODE BEGIN Init */
  /* Dual-core boot race (ROOT CAUSE of the silent VCP): on the H745 the system
   * clock is configured by CM7 (SystemClock_Config). With
   * DUAL_CORE_BOOT_SYNC_SEQUENCE disabled, CM4 runs standalone and would
   * otherwise initialise LPUART1 *before* CM7 finishes the clock setup — so the
   * UART baud is computed against the wrong kernel clock and nothing readable
   * reaches the ST-Link VCP. Spin briefly to let CM7 bring the clock up first.
   * This mirrors the known-good dual-core-logging bring-up (commit d5ba8b3);
   * replace with DUAL_CORE_BOOT_SYNC_SEQUENCE once the STOP-mode option bytes
   * are confirmed safe on hardware. */
  for (volatile uint32_t d = 0; d < 50000000U; ++d) {
    __NOP();
  }
  /* USER CODE END Init */

  /* Initialize all configured peripherals */
  MX_GPIO_Init();
  MX_DMA_Init();
  MX_BDMA_Init();
  MX_SDMMC1_SD_Init();
  MX_SPI2_Init();
  MX_SPI3_Init();
  MX_SPI4_Init();
  MX_SPI5_Init();
  MX_UART4_Init();
  MX_UART7_Init();
  MX_USART1_UART_Init();
  MX_USART3_UART_Init();
  MX_USART6_UART_Init();
  MX_CRC_Init();
  MX_I2C4_Init();
  MX_RNG_Init();
  MX_SPI1_Init();
  MX_SPI6_Init();
  MX_LPUART1_UART_Init();
  MX_UART5_Init();
  MX_UART8_Init();
  /* MX_WWDG2_Init(); -- UBC Rocket: DISABLED for bring-up.
   * CubeMX starts the WWDG2 window watchdog here, but NOTHING in the firmware
   * ever calls HAL_WWDG_Refresh. An un-refreshed WWDG2 (Counter=Window=64,
   * prescaler 1) expires within tens of microseconds, so CM4 was stuck in a
   * continuous watchdog reset loop — never reaching io_init, never running a
   * task, never transmitting a debug byte. Re-enable ONLY together with a real
   * refresh strategy (a high-priority task or timer ISR calling
   * HAL_WWDG_Refresh inside the window). Deliberate edit to CubeMX-generated
   * code — re-apply after any .ioc regeneration. */
  MX_TIM13_Init();
  MX_TIM7_Init();   /* UBC Rocket: 100 Hz baro conversion pacer (hand-added) */
  /* USER CODE BEGIN 2 */
  /* Bring up the four-layer stack on CM4 in order:
   *   IO  — start TIM13 timestamp, attach intercore HSEM, init SPI/SD/...
   *   DEV — instantiate every sensor / comms driver singleton
   *   APP — create FreeRTOS tasks and wire notify targets
   * The scheduler is then started by CubeMX's osKernelStart() below;
   * our tasks coexist with the (idle) defaultTask. */
  io_init_cm4();
  dev_init_cm4();
  app_init_cm4();
  /* USER CODE END 2 */

  /* Init scheduler */
  osKernelInitialize();  /* Call init function for freertos objects (in cmsis_os2.c) */
  MX_FREERTOS_Init();

  /* Start scheduler */
  osKernelStart();

  /* We should never get here as control is now taken by the scheduler */

  /* Infinite loop */
  /* USER CODE BEGIN WHILE */
  while (1)
  {
    /* USER CODE END WHILE */

    /* USER CODE BEGIN 3 */
  }
  /* USER CODE END 3 */
}

/**
  * @brief Peripherals Common Clock Configuration
  * @retval None
  */
void PeriphCommonClock_Config(void)
{
  RCC_PeriphCLKInitTypeDef PeriphClkInitStruct = {0};

  /** Initializes the peripherals clock
  */
  PeriphClkInitStruct.PeriphClockSelection = RCC_PERIPHCLK_ADC|RCC_PERIPHCLK_FDCAN
                              |RCC_PERIPHCLK_CKPER;
  PeriphClkInitStruct.PLL2.PLL2M = 2;
  PeriphClkInitStruct.PLL2.PLL2N = 16;
  PeriphClkInitStruct.PLL2.PLL2P = 2;
  PeriphClkInitStruct.PLL2.PLL2Q = 2;
  PeriphClkInitStruct.PLL2.PLL2R = 2;
  PeriphClkInitStruct.PLL2.PLL2RGE = RCC_PLL2VCIRANGE_3;
  PeriphClkInitStruct.PLL2.PLL2VCOSEL = RCC_PLL2VCOWIDE;
  PeriphClkInitStruct.PLL2.PLL2FRACN = 0;
  PeriphClkInitStruct.CkperClockSelection = RCC_CLKPSOURCE_HSI;
  PeriphClkInitStruct.FdcanClockSelection = RCC_FDCANCLKSOURCE_PLL2;
  PeriphClkInitStruct.AdcClockSelection = RCC_ADCCLKSOURCE_PLL2;
  if (HAL_RCCEx_PeriphCLKConfig(&PeriphClkInitStruct) != HAL_OK)
  {
    Error_Handler();
  }
}
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

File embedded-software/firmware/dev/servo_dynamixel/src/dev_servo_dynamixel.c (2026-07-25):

/**
 * @file    dev_servo_dynamixel.c
 * @brief   Robotis Dynamixel XM430-W210-T driver (Protocol 2.0).
 *
 * UBC Rocket, 2026
 */
#include "dev_servo_dynamixel.h"

#include "dxl_hal.h"
#include "io_sys/io_debug.h"
#include "io_sys/io_test_hooks.h"

#include "stm32h7xx_hal.h"

#include "FreeRTOS.h"
#include "task.h"

#include <math.h>
#include <string.h>

#define SERVO_ID_X            1u
#define SERVO_ID_Y            2u
#define MODEL_NUMBER_XM430    1030u
#define BUS_TIMEOUT_MS        20u
#define SETUP_STEP_MS         50u

#define REG_MODEL_NUMBER            0u
#define REG_OPERATING_MODE          11u
#define REG_TORQUE_ENABLE           64u
#define REG_HARDWARE_ERROR_STATUS   70u
#define REG_GOAL_VELOCITY           104u
#define REG_PRESENT_VELOCITY        128u
#define REG_PROFILE_ACCELERATION    108u
#define REG_PROFILE_VELOCITY        112u
#define REG_GOAL_POSITION           116u
#define REG_PRESENT_POSITION        132u

#define DXL_PROFILE_VELOCITY        200u   /* ~46 rpm; 0 = unlimited on XM430 */
#define DXL_PROFILE_ACCELERATION    75u    /* was 50; small bump for snappier moves */

#define OP_MODE_POSITION            3u
#define OP_MODE_EXTENDED_POSITION   4u

#define DXL_TICKS_PER_REV           4096
#define DXL_TEST_SWEEP_RANGE_DEG    90.0f
#define DXL_TEST_SWEEP_STEP_DEG     1.0f
#define DXL_TEST_SWEEP_STEP_MS      5U
#define DXL_TEST_CIRCLE_RADIUS_DEG  5.0f
#define DXL_TEST_CIRCLE_STEPS       72U
#define DXL_TEST_CIRCLE_STEP_MS     18U
#define REBOOT_DELAY_MS             500u
#define INIT_RETRY_COUNT            3u

#define DXL_TX_BUF_SIZE       DXL_MAX_PACKET_SIZE
#define DXL_RX_BUF_SIZE       DXL_MAX_PACKET_SIZE

struct servo_dynamixel {
    bool ready;
    bool id_x_ready;
    bool id_y_ready;
};

static struct servo_dynamixel s_self;

IO_TEST_HOOK_RW(s_self, struct servo_dynamixel, dev_servo_dynamixel_self)

static void reboot_id(uint8_t id);
static bool dxl_clear_hw_error_if_set(uint8_t id);
static void log_hw_error(uint8_t id);

static dxl_status_code_t bus_txrx(uint8_t id, const uint8_t *tx, size_t tx_len,
                                size_t expected_rx, dxl_status_t *st) {
    (void)id;
    uint8_t rx[DXL_RX_BUF_SIZE];
    memset(st, 0, sizeof(*st));
    return dxl_hal_txrx(tx, tx_len, rx, sizeof(rx), expected_rx, st,
                          BUS_TIMEOUT_MS);
}

void servo_dynamixel_bus_recover(void)
{
    dxl_hal_recover();
}

static bool bus_ok(dxl_status_code_t rc) {
    return rc == DXL_OK;
}

static bool bus_responded(dxl_status_code_t rc) {
    return rc == DXL_OK || rc == DXL_ERR_STATUS;
}

static void reboot_delay_ms(uint32_t ms)
{
    if (xTaskGetSchedulerState() == taskSCHEDULER_RUNNING) {
        vTaskDelay(pdMS_TO_TICKS(ms));
    } else {
        HAL_Delay(ms);
    }
}

static bool write_u8_inner(uint8_t id, uint8_t addr, uint8_t value, unsigned retries_left)
{
    uint8_t tx[DXL_TX_BUF_SIZE];
    const size_t n = dxl_pkt_build_write(tx, sizeof(tx), id, addr, &value, 1);
    if (n == 0u) return false;

    dxl_status_t st;
    const dxl_status_code_t rc = bus_txrx(id, tx, n, DXL_STATUS_MIN_LEN, &st);
    if (bus_ok(rc)) {
        return true;
    }
    if (retries_left > 0u && dxl_clear_hw_error_if_set(id)) {
        return write_u8_inner(id, addr, value, retries_left - 1u);
    }
    return false;
}

static bool write_u8(uint8_t id, uint8_t addr, uint8_t value) {
    return write_u8_inner(id, addr, value, 1u);
}

static bool write_i32_inner(uint8_t id, uint8_t addr, int32_t value, unsigned retries_left)
{
    const uint8_t data[4] = {
        (uint8_t)(value & 0xFF),
        (uint8_t)((value >> 8) & 0xFF),
        (uint8_t)((value >> 16) & 0xFF),
        (uint8_t)((value >> 24) & 0xFF),
    };

    uint8_t tx[DXL_TX_BUF_SIZE];
    const size_t n = dxl_pkt_build_write(tx, sizeof(tx), id, addr, data, 4);
    if (n == 0u) return false;

    dxl_status_t st;
    const dxl_status_code_t rc = bus_txrx(id, tx, n, DXL_STATUS_MIN_LEN, &st);
    if (bus_ok(rc)) {
        return true;
    }
    if (retries_left > 0u && dxl_clear_hw_error_if_set(id)) {
        return write_i32_inner(id, addr, value, retries_left - 1u);
    }
    return false;
}

static bool write_i32(uint8_t id, uint8_t addr, int32_t value) {
    return write_i32_inner(id, addr, value, 1u);
}

static bool read_bytes(uint8_t id, uint8_t addr, uint16_t len, uint8_t *out) {
    uint8_t tx[DXL_TX_BUF_SIZE];
    const size_t n = dxl_pkt_build_read(tx, sizeof(tx), id, addr, len);
    if (n == 0u) return false;

    dxl_status_t st;
    if (!bus_ok(bus_txrx(id, tx, n, dxl_pkt_expected_read_rx(len), &st))) {
        return false;
    }
    if (st.param_len < len) return false;
    memcpy(out, st.params, len);
    return true;
}

static bool read_u16(uint8_t id, uint8_t addr, uint16_t *out) {
    uint8_t data[2];
    if (!read_bytes(id, addr, 2, data)) return false;
    *out = (uint16_t)data[0] | ((uint16_t)data[1] << 8);
    return true;
}

static bool read_i32(uint8_t id, uint8_t addr, int32_t *out) {
    uint8_t data[4];
    if (!read_bytes(id, addr, 4, data)) return false;
    *out = (int32_t)((uint32_t)data[0]
           | ((uint32_t)data[1] << 8)
           | ((uint32_t)data[2] << 16)
           | ((uint32_t)data[3] << 24));
    return true;
}

/* Hardware Error Status (addr 70) is read-only; reboot clears latched faults. */
static bool read_hw_error(uint8_t id, uint8_t *hw_out)
{
    return read_bytes(id, REG_HARDWARE_ERROR_STATUS, 1, hw_out);
}

static bool dxl_clear_hw_error_if_set(uint8_t id)
{
    uint8_t hw = 0;
    if (!read_hw_error(id, &hw)) {
        return false;
    }
    if (hw == 0u) {
        return false;
    }

    io_debug_printf("DXL id%u hw_err=0x%02x, rebooting to clear\r\n",
                    (unsigned)id, (unsigned)hw);
    reboot_id(id);
    return true;
}

static void log_hw_error(uint8_t id) {
    uint8_t hw = 0;
    if (!read_hw_error(id, &hw)) {
        io_debug_printf("DXL id%u hw_err=READ FAIL\r\n", (unsigned)id);
        return;
    }
    io_debug_printf("DXL id%u hw_err=0x%02x\r\n", (unsigned)id, (unsigned)hw);
    if (hw != 0u) {
        reboot_id(id);
    }
}

static void reboot_id(uint8_t id) {
    uint8_t tx[DXL_TX_BUF_SIZE];
    const size_t n = dxl_pkt_build_reboot(tx, sizeof(tx), id);
    if (n == 0u) {
        return;
    }

    dxl_status_t st;
    (void)bus_txrx(id, tx, n, DXL_STATUS_MIN_LEN, &st);
    reboot_delay_ms(REBOOT_DELAY_MS);
}

static bool ping_id(uint8_t id, uint8_t *pkt_error) {
    uint8_t tx[DXL_TX_BUF_SIZE];
    const size_t n = dxl_pkt_build_ping(tx, sizeof(tx), id);
    if (n == 0u) return false;

    dxl_status_t st;
    const dxl_status_code_t rc =
        bus_txrx(id, tx, n, DXL_PING_RESPONSE_LEN, &st);
    if (!bus_responded(rc)) {
        return false;
    }
    if (pkt_error != NULL) {
        *pkt_error = st.error;
    }
    return true;
}

static int32_t zero_ticks_for_id(uint8_t id)
{
    if (id == SERVO_ID_Y) {
        return DXL_ZERO_TICKS_Y;
    }
    return DXL_ZERO_TICKS_X;
}
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

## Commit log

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2026-03-10 docs: update CODEOWNERS, branching model, and team leads
    Rewrite CODEOWNERS with correct embedded-software/ paths and tvr-* team handles.
    Simplify branching model to two-tier (feature → stage → main).
    Add team leads table to CONTRIBUTING.md.
    [SensorDataModel.cpp, SensorDataModel.h, main.c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]
2026-03-11 Consolidate ring buffers, GPS struct, and timestamp into shared libs
    Replace 6 copy-pasted SPSC ring buffer implementations (accel, gyro,
    ms5611, ms5607, GPS fix, radio msg) with a single generic
    SPSC_RING_DECLARE macro in libs/collections/. Extract the shared
    gps_fix_t struct into libs/gnss-protocol/ so both boards use one
    definition. Move the DWT timestamp utility from the FC into
    libs/timestamp/ for cross-board reuse.
    [protocol_config.h]
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2026-03-20 added EKF tests, made EKF library more independent of the firmware, changed it to be a error state kalman filter, fixed a covariance update issue...
    [main.c, ulysses.ioc]
2026-03-22 feat: add force to pwm mapping (#18)
    * firmware/controls/pwm: add pwm module header
    * Create test_pwm.c
    * pwm tests
    * firmware/controls/pwm: add pwm module source
    * firmware/controls/tests: add pwm tests to unity test list
    * firmware/controls/tests: fix pwm tests
    * firmware/controls/pwm: add additional doc comments
    * firmware/controls/pwm: remove unecessary assignment
    * firmware/controls/tests: update CMakeLists to include pwm tests
    ---------
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2026-03-28 added omega_b in state_snapshot, Calibration biases, GPS fix, and Control output for SD card logging
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2026-04-04 feat: unified SD logging pipeline with reliable FreeRTOS trace
    Redesign the SD card logging architecture to support high-throughput
    FreeRTOS trace capture alongside regular sensor logging.
    Firmware changes:
    - Replace ring buffer + flush task with unified sector buffer pool
    (10 buffers: 4 log + 6 trace, partitioned to prevent starvation)
    - Trace hooks write 12-byte events directly into 512-byte sectors
    (lock-free, no mutex, ~40 cycles per hook call)
    - DMA completion ISR wakes flush task for back-to-back writes
    - Fix timestamp_update() never being called (DWT wrapped at 17.18s)
    - Increase FreeRTOS heap from 8KB to 24KB (was exhausting on task creation)
    - Assign task numbers via vTaskSetTa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
2026-04-04 fix: non-blocking log mutex, SD init, stack overflow, flight header
    - log_writer_append_record: non-blocking mutex (timeout=0) so the
    controls task never stalls on logging contention
    - log_writer_flush: 5ms timeout instead of portMAX_DELAY
    - sd_flush_task_start: call log_writer_init() + log_service_mark_ready()
    (was missing after rebase — logging never initialized)
    - sd_flush_task_start: write flight_header on startup so decoder can
    find flights with --latest-flight
    - trace_hooks: guard log_writer_ready() before claiming buffers to
    prevent writing to uninitialized context
    - StateEstimation stack: 512*4 -> 2048*4 (orientation_predict allocates
    four 9x9 float matrices = 1.3KB on st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
2026-04-05 feat: EKF sparse block predict + fixed-dim matrix ops (90% → ~40% CPU)
    EKF optimization:
    - orientation_predict: exploit F matrix sparsity — compute P = F*P*F^T
    using 3x3 block operations instead of full 9x9 dense multiplications.
    Reduces FLOPs from 1458 to ~270 per call (called 1700x/sec).
    - measurement_update: replace generic mat_mul() with fixed-dimension
    inline functions (matN_mul_Nx3, matN_mul_3x3, etc.) so the compiler
    can unroll loops and schedule FMA instructions.
    - Add -O3 -funroll-loops for state_estimation library.
    - All EKF unit tests pass.
    SD logging:
    - Bump preflight erase from 64 MB to 128 MB (~9 min of logging).
    - Disable runtime erase-ahead (caused 25ms HAL busy-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
2026-04-06 refactor: fix pid error accumulation
    Flight controls algorithm should only be ran during flight to prevent error accumulation in PID controller.
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2026-04-08 fix: controls spec compliance — Kp/Kd gains, thrust direction, gyro sign
    - compute_command_torque: add Kp and Kd gain matrices + angular rate
    feedback (spec eq 3.8). Was using raw phi with no gains or damping.
    - update_thrust_direction: use -z convention (spec eq 5.6). Was using
    +z which flipped s_t_hat from [0,0,-1] to [0,0,+1] after first step.
    - compute_gimbal_angles: match spec eq 5.7 signs for -z convention.
    - compute_gyroscopic_torque: omega x (I*omega), not (I*omega) x omega.
    - compute_thrust_magnitude: negate dot product for -z thrust convention.
    - Update all 93 unit tests to match corrected pipeline. 0 failures.
2026-04-10 refactor: replace dshot with bdshot
    [bdshot.c]
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2026-05-09 refactor: replace HAL with LL
    Fixes issue where when there are more than one active channel on a TIM instance, after the first transfer complete interrupt for one of the channels, all following channels will randomly drop to a low state and is stuck there until the next frame.
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2026-05-09 refactor: fix check allowing invalid throttle values
    [bdshot.c]
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2026-05-17 Servo code fix and calibarated
    [main.c]
2026-05-17 refactor: H747 dual-core HW/IO/DEV/APP layering
    Replace the single-core H5 + G0 firmware tree with a dual-core STM32H747
    flight controller and a clean four-layer architecture. The old H5 + G0
    trees move to depracated/; live code now sits under flight_controller/
    (CubeMX), io/, dev/, app/, and lib/.
    Highlights:
    - HW: flight_controller/ holds the dual-core CubeMX project (CM4 + CM7).
    - IO: io/io/ + io/io_sys/ split (transport vs system services). Helper
    libs io/io_spi_queue/, io/io_uart_dma_cm/, io/io_intercore_slot/. Per-
    target impls under io/h747/CM{4,7}/.
    - DEV: opaque-singleton drivers under dev/ — dev_imu_bmi088,
    dev_imu_icm40609, dev_baro_ms5611, dev_gps_nmea, dev_radio_rfd900,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
    [dev_baro_ms5611.c, dev_imu_bmi088.c, dev_imu_icm40609.c]
2026-05-17 fix: wire main.c boot path; drop orphaned legacy directories
    The previous commit added the new io/ + dev/ + app/ + flight_controller/
    + depracated/ trees but didn't actually call any of our code from the
    CubeMX-generated main() — boot would have reached osKernelStart() with
    only the idle defaultTask. Wire each core's USER CODE BEGIN blocks to
    call the four-phase init:
    CM4: io_init_cm4 → dev_init_cm4 → app_init_cm4 → (osKernelStart)
    CM7: io_init_cm7 → dev_init_cm7 → app_init_cm7 → (osKernelStart)
    USER CODE BEGIN Includes pulls io_sys/io_init.h and app/app_init.h on
    both cores. CubeMX's osKernelInitialize() + MX_FREERTOS_Init() +
    osKernelStart() block remains untouched (reg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
    [main.c, main.h, protocol_config.h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]
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2026-05-17 revert on firmware code
    [SensorDataModel.cpp]
2026-05-17 fix: cross-core shared SRAM4 + IRQ glue; both ELFs link clean
    Closes the four blockers between "code compiles" and "firmware can be
    flashed and exercised on the H747":
    - SRAM4 (.shared) section added to CM4 + CM7 linker scripts at
    0x38000000 (D3 domain, uncached on both cores). app/shared/
    shared_memory.c moved into .shared via __attribute__((section)).
    Verified __shared_region_start__ resolves to the same physical
    address on both ELFs.
    - UART CMF dispatch wired in CM4 stm32h7xx_it.c for huart4/5/7
    (mmWave / GPS / radio) — checks UART_FLAG_CMF before HAL_UART_IRQ-
    Handler and routes to io_uart_on_match_isr (declared via void* in
    io_uart.h so the header stays HAL-independent)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
    [dev_radio_rfd900.c, io_uart.c, main.c]
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2026-05-24 refactor: fixes for telemetry and checksum being inverted for telemetry
    [bdshot.c]
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2026-05-30 refactor: fix include paths
    [main.c]
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2026-05-31 refactor: fix potential race condition with command frames
    Race condition exists on the is_command_frame field, where the flag could be set to a different value before the dma_transfer_complete_callback reads it. This can potentially lead to a situation where we try to read telemetry data for a command.
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2026-05-31 feat(messages): add message registry foundation (schema + strawman)
    Single-source-of-truth JSON registry for all structured I/O between
    firmware, ground station, jetson, and tools. Sits at embedded-software/
    messages/ so all consumers can reach it.
    Two-class encoding:
    - Class A: packed records, fixed schema, hot path. Codegen produces
    packed C structs + memcpy publish.
    - Class B: nanopb envelope, flexible schema, sporadic. Codegen will
    emit an auto-generated .proto, then nanopb compiles it.
    Both share one envelope, one routing table, one publish API. The
    registry is the source of truth — .proto files, C headers, Python
    decoder, routing table, error annotation strings all derive from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
2026-05-31 feat(messages): add phase-1 codegen tool + generated headers
    Phase-1 codegen for the message registry: emits packed C structs and the
    routing table for Class A messages so firmware can memcpy onto the wire.
    Class B + commands + .proto generation are explicitly out of scope (warned
    + skipped) — those land in phase 2.
    Tool layout (embedded-software/messages/codegen/, stdlib + jsonschema only):
    - loader.py: JSON Schema validation + hand-rolled semantic checks
    (duplicate ids, unknown channel refs, type cycles, contiguous channel_ids).
    - types_resolve.py: C type mapping + packed sizes + topo-sorted user types.
    - linter.py: bus-budget check (rate × wire_size × 8 vs max_wire_bps per
    channe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
2026-05-31 feat(messages): integrate firmware runtime + align CRC32 across all sides
    Bundles RT's firmware runtime library (lib/messages/) with the CMake
    wire-up into both per-core builds and a CRC32-alignment fix on the
    Python decoder.
    - lib/messages/: envelope assembly (length + class + module_id +
    msg_id + t_us_publish + payload + crc16), routing fan-out, per-
    channel token bucket, drop counter publish. Uses CRC-16/CCITT-FALSE
    (poly 0x1021, init 0xFFFF, no reflect, no xor). 16 host-side Unity
    tests pass.
    - Exposes messages_sd_sink_set(fn) instead of calling log_writer
    directly — the existing log_writer wraps every payload in its own
    log_record_frame_t, which would double-wrap our enve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
2026-05-31 feat(messages): Class B proto3 encoding (codegen .proto + nanopb + decoder)
    Codegen (W1B):
    - emit_proto.py walks every Class B message and every command's
    request/response, emits proto3 schema to firmware/generated/proto/
    messages.proto. User types are emitted only if referenced (cleaner
    proto). Field numbers come from registry declaration order, matching
    the decoder's descriptor builder so wire encoding aligns.
    - cli.py now invokes the vendored nanopb_generator
    (libs/rocket-protocol/nanopb/) on the emitted .proto to produce
    messages.pb.{c,h}. --no-nanopb skips for environments without
    protobuf+grpcio-tools (CI installs them). Default generator path is
    resolved relative to th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
2026-05-31 feat(messages): inbound command dispatcher + system.get_build_info
    Adds the bidirectional half: firmware can receive command requests,
    look up registered handlers, invoke them, and ship responses back on
    the same channel.
    Wire-format additions:
    - Two new class bytes: MSG_CLASS_CMD_REQ (0x43) and MSG_CLASS_CMD_RESP
    (0x44). The envelope shape is unchanged; the class byte distinguishes
    pub/sub messages from request/response so cmd_id and msg_id don't
    collide in the same module (system has both msg_id=1 and cmd_id=1).
    - msg_id field carries cmd_id when class is CMD_REQ/CMD_RESP.
    Runtime:
    - messages_register_command_handler(module_id, cmd_id, fn) — linear
    registry, 16 slots, replace-i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
2026-06-01 feat(messages): real lwIP UDP channel — udp_recv + udp_sendto
    Replaces the stub udp_sink with the lwIP-raw shape that was sketched
    inline in messages_udp.c, now that the LwIP middleware is on disk.
    - udp_rx_cb runs on tcpip_thread: copies the pbuf chain into a stack
    scratch buffer, calls messages_handle_inbound(CH_UDP, …), pbuf_free.
    Also remembers the sender's IP:port so responses go back to the last
    requester — fine for a single ground station; will need a per-
    request destination when we multiplex.
    - udp_sink runs on any task: wraps with LOCK_TCPIP_CORE() (lwIP raw
    API is single-threaded; CORE_LOCKING is on by default in 2.x), then
    pbuf_alloc + udp_sendto + pbuf_free. R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
2026-06-01 feat(messages): move VCP onto IO_UART_DEBUG (hlpuart1)
    The IOC now exposes LPUART1 as the debug port with full BDMA RX
    (circular) + BDMA TX + NVIC IRQ. Switching the messages VCP channel
    off the mmWave parking spot.
    - Add IO_UART_DEBUG to the io_uart public API (extern decl in io_uart.h,
    definition in CM4/io_uart.c pointing at hlpuart1 with match_byte=0x00
    for COBS framing). Its own 512 B circular buffer + 512 B scratch.
    - Add IO_UART_DEBUG to the streaming-UART dispatch table so
    io_uart_on_match_isr routes correctly when LPUART1 fires.
    - Add CMF dispatch in LPUART1_IRQHandler USER CODE block — same shape
    as UART4/5/7. Checks UART_FLAG_CMF before HAL_UART_IRQHandler clears
    anyth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
    [io_uart.c, ulysses-fc.ioc]
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2026-06-01 feat(app): wave 1 task bodies — state est, mission mgr, controls self-test, crash dump
    Four parallel-agent task-body migrations from the deprecated H5
    firmware, integrated as one coherent landing.
    state_estimation_task (cm4/state_estimation_task.c, 432 lines):
    - Full ESKF wired with ICM-40609 as primary IMU (drives predict),
    BMI088 as secondary (kept hot for ring health + 50 ms failover).
    - Boot calibration: eskf library accumulates bias for 4000 samples
    before transitioning to predict/update. State is published as
    identity/zero during the window so CM7 controls never sees a stale
    reader.
    - Baro: EMA smoothing + reference height locked on first sample;
    height relative to launch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
2026-06-01 feat(app): wave 2 — CM7→CM4 log handoff + SD writer body
    Closes the cross-domain logging gap and gives sd_log_task a real body.
    Records published from CM7 now reach the SD card via a lock-free SPSC
    ring in SRAM4, drained by CM4's sd_log_task.
    CM7→CM4 SRAM4 SPSC ring:
    - Grew APP_SHARED_REGION_SIZE 4 KB → 16 KB to fit the 8 KB ring data
    plus 32 B header. Old 64-byte LOG_HANDOFF stub slot replaced.
    - Ring header lives at APP_SLOT_LOG_HANDOFF_RING_OFFSET (0x0800):
    head (CM7 writes), tail (CM4 writes), drops, pushed, magic (LOGR).
    - Lock-free SPSC: each side only writes its own index, reads the
    other's with DMB. SRAM4 is uncached on both cores so no cache dance.
    - CM7 raises IO_IC_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
2026-06-02 feat(dev): MMC5983MA magnetometer driver
    New device driver at dev/mag_mmc5983/ — written from the MEMSIC
    MMC5983MA datasheet (rev D, 2019) since no driver source for this
    chip exists anywhere in the repo's history (origin has 49 remote
    branches, all 433 commits searched).
    Hardware:
    - SPI device on IO_SPI_MMC (= SPI1 on the CM4 side per the IOC's
    user-constants block: SPI_MMC5983MA-CortexM4, SPI1).
    - DRDY input wired through IO_EXTI_MMC_INT (PG6, already in the
    io_exti table and dispatched via EXTI9_5).
    Driver scope:
    - 4-wire SPI framing (1st byte = {RW:1, ADDR:7}).
    - Software-reset → product-ID verify (must read 0x30) at init.
    - 100 Hz continuous measurement mode with auto-SET/RESE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
    [dev_mag_mmc5983.c]
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2026-06-02 fix(mag): proper SET/RESET offset cancellation + ISR-safe SPI
    Self-audit caught three real bugs in the wave-1-quality mag driver:
    1. Uncalibrated busy-loop "delay" for the 10 ms post-reset settle —
    replaced with HAL_Delay (SysTick is up before our code runs).
    2. Blocking SPI from the EXTI ISR — replaced with a dedicated mag
    service task; EXTI just does xTaskNotifyFromISR.
    3. The big one: no offset cancellation. Original used continuous mode
    with PRD_SET, which is a degauss schedule, NOT offset cancellation.
    The MMC5983MA's claim-to-fame is the SET/RESET differencing protocol
    where SET and RESET pulses produce opposite-sign magnetic offsets:
    field = (M_set - M_rese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
    [dev_mag_mmc5983.c]
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2026-06-14 feat(state-est): wire MMC5983 mag into EKF + mag.sample + auto-cal persist
    Registry: new mag module (id=3) with mag.sample (t_us, field,
    offset, temp_c) routed to SD @ 100 Hz, plus ring_overflow /
    spi_fault error codes. Regenerated messages codegen.
    dev_mag_mmc5983: new mag_mmc5983_get_offset() accessor surfaces
    the driver's live (M_set + M_reset)/2 hard-iron estimate.
    state_estimation_task:
    - ESKF_SENSOR_MAG noise config (R=0.05 on the unit-normalized
    field — loose enough to ignore ferrous-structure / motor-current
    anomalies without de-tuning yaw observability).
    - Drains the mag ring each cycle, applies per-axis soft-iron
    scale from g_storage.payload.calibration.mag_scal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
    [dev_mag_mmc5983.c]
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2026-06-28 fix(dev/dshot): fix incorrect DMA increment mode
    [bdshot.c]
2026-06-28 Revert "fix(dev/dshot): fix incorrect DMA increment mode"
    This reverts commit 89e6736d4737a1c72b41510ccf8555a10a39baff.
    [bdshot.c]
2026-06-28 fix(dev/dshot): fix DShot DMA transfer not starting
    [bdshot.c]
2026-06-28 fix(dev/dshot): fix stale data in DShot RX buffer
    [bdshot.c]
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2026-06-30 fix(dev/dshot): fix incorrect size being used for receive edges calculation
    The STM32H5XX DMA peripheral holds the number of bytes in its counter. However, the STM32H7XX uses the number of items (depends on the set data size).
    [bdshot.c]
2026-06-30 fix(dev/dshot): fix incorrect increment being used for RX
    [bdshot.c]
2026-06-30 fix(dev/dshot): fix incorrect size being used for DCACHE clean and invalidate
    STM32H7XX DCACHE takes in the number of bytes of memory to invalidate or clean, not the number of 32-bit blocks.
    [bdshot.c]
2026-07-05 end to end bring up, free CM7, skip BMI and MAG
    [dev_imu_bmi088.c, main.c]
2026-07-05 updated for imu fix (dma callback and dangling pointer))
    [flight_controller.cfg]
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2026-07-05 feat(gcs): port new UWB ground control station onto h747-bsp refactor
    Brings the reworked ground control station from embedded-software/stage
    onto the h747-bsp refactor branch, plus the additive protocol changes it
    depends on. Firmware changes from stage are intentionally excluded.
    Ground station:
    - New Probe Map, Radio Console, Radio Output, and Tuning panels
    - PresetManager + pid_presets.json for PID gain presets
    - Reworked System Health / State & Position / PID panels, themed controls
    - Removes legacy RadioTestWindow / RadioOutputWindow / Panel_Control
    Protocol (libs/rocket-protocol, additive & backward-compatible):
    - common.proto: new Vec2 message
    - command.proto: new SetProbeLayo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
    [pid_presets.json]
2026-07-06 refactor(proto+gcs): remove gps_connected from SystemStatus
    GPS was dropped in favour of UWB probes, and the board no longer reports
    it. Completes the removal started in the previous commit (firmware side):
    - status.proto: field 8 removed; tag + name reserved so they are never
    reused with a different meaning
    - status.pb.h regenerated with the vendored nanopb generator (max
    encoded size 42 -> 40)
    - GCS SensorDataModel: gpsConnected property/getter/members, GPS alarm
    chips, raw-log line, and CSV columns removed (TELEM row padding
    adjusted to keep columns aligned)
    Wire-compatible in both directions during rollout: proto3 decoders
    skip/omit the missing field.
    Verified: CM4 firmware an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
    [SensorDataModel.cpp, SensorDataModel.h]
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2026-07-12 feat: GCS heartbeat keep-alive, radio log auto-clear, drop baro UI
    - CommandSender sends CMD_NONE at 4 Hz whenever a port is open so the
    FC's 500 ms heartbeat watchdog no longer auto-disarms after ARM
    - Panel_Radio_Output clears the raw packet log every 10 s (unbounded
    QString rebind per packet was lagging the UI)
    - remove baro1Ok/baro2Ok properties, health chips, alarm chips and CSV
    columns (no baro in the downlink contract)
    [SensorDataModel.cpp, SensorDataModel.h]
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2026-07-18 fix(cm4): bring up MMC5983 + BMI088 SPI; fix mag pre-scheduler task hang
    SPI clocks were at the CubeMX default /2, far over the sensors' max
    (SPI1 32MHz, SPI4 60MHz vs 10MHz limit), so BMI088 + MMC5983 init were
    commented out. Retune prescalers in the .ioc and spi.c:
    - SPI1 /8 = 8 MHz (MMC5983 mag, 10MHz max)
    - SPI2 /8 = 4 MHz (MS5611 baro, 20MHz max)
    - SPI4 /16 = 7.5 MHz (BMI088 imu, 10MHz max)
    and re-enable both inits in dev_init_cm4.
    Fix a boot hang uncovered by enabling the mag: mag_mmc5983_init()
    called xTaskCreateStatic() during the DEV phase, before the scheduler.
    FreeRTOS uxCriticalNesting is 0xaaaaaaaa until vTaskStartScheduler, so
    the critical section inside task cr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
    [dev_mag_mmc5983.c, ulysses-fc.ioc]
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2026-07-19 fix(mag): poll STATUS for measurement-done; separate SET/TM_M writes
    The MMC5983 was producing ZERO samples — the service task stalled
    forever waiting on a DRDY/EXTI edge that never came. Three fixes:
    1. Poll STATUS.Meas_M_Done instead of waiting on the DRDY interrupt.
    The INT pin never produced catchable edges on this board; the part
    is slow (~4 ms/measurement) so a 1 ms poll costs little. The mag now
    produces samples and the readiness gate reports mag=READY on its own.
    2. Split the SET/RESET degauss pulse and the TM_M measurement trigger
    into two separate CTRL_0 writes. Combining them fires the coil but
    the measurement never runs.
    3. Clear Meas_M_Done (write-1-to-clear)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
    [dev_mag_mmc5983.c]
2026-07-19 fix(mag): settle SET/RESET before measuring — real field, no timeouts
    The SET/RESET offset-cancellation wasn't flipping the sensor: the SET
    and RESET halves came back with the SAME polarity, so the differenced
    field collapsed to ~0 (M_set ~= M_reset, ~0.5 mG) while the offset ate
    the whole ~0.87 G reading. That left EKF yaw with no usable field.
    Root cause: TM_M was fired immediately after the SET/RESET pulse, so
    the measurement sampled the pre-magnetization state. Adding a 1 ms
    settle (MAG_SETRESET_SETTLE_MS) between the pulse and TM_M — matching
    SparkFun's driver — fixes it. Verified on hardware:
    M_set = 16074, -1484, -11616
    M_reset = -16841, +3216, +12820 (polarity flip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
    [dev_mag_mmc5983.c]
2026-07-19 docs(mag): correct Meas_M_Done comment per datasheet
    TM_M auto-clears Meas_M_Done on the next measurement (datasheet p.14),
    so the explicit write-1 clear is belt-and-suspenders (+ INT-latch
    hygiene), not a stale-read guard as the old comment claimed. The real
    SET/RESET fix was the post-pulse settle delay (c12d6d8). Also confirmed
    Auto_SR_en is never set, so manual SET/RESET is not overridden.
    [dev_mag_mmc5983.c]
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2026-07-25 fix(dev/bdshot): fix DCACHE unaligned DMA and incorrect gpio pin (#73)
    * fix(dev/bdshot): fix DMA buffer not being DCACHE aligned
    * fix(dev/bdshot): fix LL pin being used for HAL pin in RAL call
    [bdshot.c]
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2026-07-25 fix(dev/bdshot): fix DCACHE unaligned DMA and incorrect gpio pin
    [bdshot.c]
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2026-07-25 fix(controls): revert "esc pwm update"
    This reverts commit bf4e9178cef637af8994497fd0648f41a9e97e67.
    [ulysses-fc.ioc]
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

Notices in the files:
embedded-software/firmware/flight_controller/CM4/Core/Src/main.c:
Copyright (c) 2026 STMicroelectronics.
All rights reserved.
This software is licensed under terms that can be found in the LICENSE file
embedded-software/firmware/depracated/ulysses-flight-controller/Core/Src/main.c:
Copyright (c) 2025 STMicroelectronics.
